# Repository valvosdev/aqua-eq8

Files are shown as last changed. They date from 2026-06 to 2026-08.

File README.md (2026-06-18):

# Aqua:eq8

> Open Hardware. Open Source. Smart Irrigation.

Aqua:eq8 is an open-source and open-hardware 8-zone smart irrigation controller designed for residential, commercial, greenhouse, and agricultural installations.

Built around the ESP32-C3-MINI-N4, Aqua:eq8 combines reliable irrigation control with secure connectivity, mobile management, OTA firmware updates, MQTT communication, and cloud integration while remaining fully self-hostable and hackable.

The project includes:

- ESP32 firmware
- Hardware schematics and PCB design
- Golang backend API
- React Native mobile application
- Docker, Kubernetes, and Helm deployment support

---

## Features

### Irrigation Control

- 8 independent irrigation zones
- Multiple zones can run simultaneously
- Configurable Master Valve support
- Configurable pump start delay
- Local manual operation without Internet
- Mobile application control
- MQTT-based communication
- Future scheduling support
- Future weather integration
- Emergency stop functionality

### Connectivity

- WiFi provisioning via BLE
- Bluetooth Low Energy onboarding
- MQTT communication
- OTA firmware updates
- Cloud synchronization
- Device telemetry

### Security

- ESP32 Secure Boot
- Flash Encryption
- Signed OTA updates
- TLS communication
- Device authentication
- Secure credential storage

### Reliability

- Offline-first operation
- Local control during Internet outages
- Hardware watchdog
- Software watchdog
- Automatic recovery
- Power-loss recovery

### Open Source

- Open firmware
- Open hardware
- Open API
- Open mobile app
- Self-hostable backend

---

# Repository Structure

```
aqua-eq8/
├── firmware/
│   ├── main/
│   ├── components/
│   ├── ble/
│   ├── wifi/
│   ├── mqtt/
│   ├── ota/
│   └── valve/
│
├── hardware/
│   ├── schematic/
│   ├── pcb/
│   ├── enclosure/
│   └── bom/
│
├── api/
│   ├── cmd/
│   ├── internal/
│   ├── deployments/
│   ├── helm/
│   └── docker/
│
├── mobile/
│   ├── src/
│   ├── ios/
│   └── android/
│
└── docs/

```

# Hardware

## Power

The controller is powered by a standard irrigation transformer.

### Input

text 24VAC Barrel Jack 

### Internal Rails

```
text 24VAC  ├── Valve Outputs  ├── Current Monitoring  └── AC/DC Converter       ├── 5V       └── 3.3V 
```
---

## Main Components

### MCU

- ESP32-C3-MINI-N4
- WiFi 2.4GHz
- Bluetooth Low Energy
- 4MB Flash

### Output Expansion

Two 74HC595 shift registers are used:

#### Shift Register #1

Controls:

- 8 TRIAC outputs
- 8 Green status LEDs

#### Shift Register #2

Controls:

- 8 Red Master LEDs

This minimizes GPIO usage while allowing future expansion.

### Valve Drivers

- TRIAC-based switching
- Designed for 24VAC sprinkler valves
- RC snubber protection per channel
- Future current sensing support

### Protection

- Input fuse
- Snubber protection on every channel
- Brownout protection
- Hardware watchdog
- Secure boot
- Flash encryption

---

# Channel Controls

## Channels 1-8

Each button controls one irrigation zone.

### Short Press

Toggle zone state.

| Current State | Action |
|---|---|
| OFF | Turn ON |
| ON | Turn OFF |

### Long Press

Toggle Master Valve assignment.

| Current State | Action |
|---|---|
| Normal Zone | Set as Master |
| Master Zone | Remove Master |

Only one channel may be configured as Master at a time.

---

# Master Valve Operation

A Master Valve is commonly used for:

- Main water supply
- Pump control
- Pressure system enable

When any non-master zone is enabled:

1. Master Valve turns ON immediately
2. Zone enters waiting state
3. Configurable delay timer starts
4. Zone activates after delay

Example:

text Channel 1 = Master  User enables Channel 3  Channel 1 ON immediately  Channel 3 LED flashes  5 second delay  Channel 3 ON 

When the last active zone stops:

text Channel 3 OFF  No active zones remaining  Channel 1 OFF 

### Default Delay

yaml master_delay_seconds: 5 

Configurable through the mobile application.

---

# Channel LED Behavior

Each channel button contains:

- Green LED
- Red LED

## Green LED

Indicates operational state.

| State | Green |
|---|---|
| OFF | OFF |
| Waiting Master Delay | Flashing |
| Active | Solid |

## Red LED

Indicates configuration state.

| State | Red |
|---|---|
| Normal Zone | OFF |
| Master Zone | Solid |

## Combined States

| State | Green | Red |
|---|---|---|
| OFF | OFF | OFF |
| ON | ON | OFF |
| Master OFF | OFF | ON |
| Master ON | ON | ON |
| Waiting Delay | Flashing | OFF |

---

# Status Button (Button 9)

Button 9 is a dedicated RGB status and management button.

Functions:

- Device Status
- BLE Pairing
- Factory Reset

---

## RGB Status LED

The status LED always displays the highest priority state.

Priority:

text Error OTA Update BLE Connected BLE Advertising WiFi Connected Booting 

### States

| State | RGB |
|---|---|
| Booting | White Breathing |
| WiFi Connected | Solid Green |
| BLE Advertising | Blue Breathing |
| Mobile App Connected | Solid Blue |
| OTA Update | Purple Breathing |
| Error | Red Flashing |

---

## Button Actions

### Short Press

Enable BLE pairing mode.

LED:

text Blue Breathing 

Duration:

text 10 Minutes 

### Long Press (10 Seconds)

Factory Reset.

Deletes:

- WiFi Credentials
- MQTT Configuration
- Device Pairing
- Local Configuration
- Schedules

LED:

text Red Breathing 

Device automatically reboots.

---

# Connectivity

Aqua:eq8 intentionally avoids:

- Captive Portals
- Access Point Setup
- Embedded Web UI

All device provisioning is performed through Bluetooth Low Energy.

### Provisioning Flow

text Power Device       ↓ Press Status Button       ↓ BLE Pairing       ↓ Mobile App       ↓ Send WiFi Credentials       ↓ Connect to Network       ↓ Register with Backend       ↓ MQTT Connected 

---

# MQTT

MQTT is the primary communication mechanism between the controller and backend services.

## Topics

text aquaeq8/{deviceId}/state aquaeq8/{deviceId}/events aquaeq8/{deviceId}/telemetry aquaeq8/{deviceId}/command aquaeq8/{deviceId}/ota 

## Example Telemetry

json {   "uptime": 86400,   "wifi_rssi": -62,   "free_heap": 124832,   "active_zones": [2,4,7] } 

MQTT data can be consumed directly by:

- Telegraf
- InfluxDB
- TimescaleDB
- VictoriaMetrics
- Grafana

---

# Firmware

Location:

text /firmware 

Built using:

- ESP-IDF
- FreeRTOS
- C/C++

## Features

### Device Control

- Zone management
- Master Valve logic
- Delay handling
- Local operation

### Connectivity

- BLE provisioning
- WiFi management
- MQTT client

### OTA

- Signed firmware updates
- Rollback protection
- Secure update process

### Security

- Secure Boot
- Flash Encryption
- Device authentication

### Reliability

- Hardware watchdog
- Software watchdog
- Crash recovery

---

# Backend API

Location:

text /api 

Built using:

- Go 1.26+
- PostgreSQL
- Redis
- MQTT

## Features

### Device Management

- Device registration
- Pairing
- Configuration synchronization

### Monitoring

- Online/offline status
- Telemetry collection
- Device diagnostics

### Security

- JWT authentication
- TLS communication
- API rate limiting

---

# Deployment

## Docker

bash docker compose up -d 

## Kubernetes

bash kubectl apply -f deployments/ 

## Helm

bash helm install aquaeq8 ./helm 

---

# Mobile Application

Location:

text /mobile 

Built using:

- React Native
- TypeScript

## Features

### Device Setup

- BLE discovery
- WiFi provisioning
- Device pairing

### Device Management

- Zone control
- Master Valve configuration
- Delay configuration

### Monitoring

- Device health
- Connectivity status
- Telemetry visualization

### OTA

- Firmware update notifications
- Update progress monitoring

---

# Future Features

## Planned

- Irrigation schedules
- Weather integration
- Rain delay
- Seasonal adjustments
- Water usage analytics

## Hardware Expansion

- Flow meter support
- Rain sensor input
- Valve current monitoring
- Leak detection
- Pump monitoring

---

# Valve Current Monitoring

Future versions may include electrical current sensing on each output channel.

Benefits:

- Detect disconnected valves
- Detect broken wires
- Detect short circuits
- Detect stuck valves
- Improve diagnostics

Example:

text Zone 4 ON  Expected Current: 220mA Measured Current: 0mA  Alert: Valve Not Connected 

---

# Development

## [Firmware](firmware)

bash cd firmware  idf.py build idf.py flash idf.py monitor 

## [Backend](api)

bash cd api  go run ./cmd/server 

## [Mobile](mobile)

bash cd mobile  yarn install

bash cd mobile  yarn install yarn start 

---

# Security Model

Every controller includes:

- Unique Device ID
- Device Certificate
- Private Key

Firmware security:

- Secure Boot enabled
- Flash Encryption enabled
- Signed OTA updates only

The controller never accepts unsigned firmware images.

---

# Contributing

Contributions are welcome.

Areas where help is needed:

- Embedded development
- Hardware design
- Backend development
- Mobile development
- Testing
- Documentation

Please open an issue or submit a pull request.

---

# License

MIT License

See [LICENSE](LICENSE) for details.

---

# Philosophy

Aqua:eq8 is built around three principles.

## Open Source

All software is publicly available.

## Open Hardware

PCB layouts and schematics are publicly available.

## Local First

Your irrigation system continues operating even if the Internet does not.

---

Aqua:eq8

An open-source, secure, MQTT-native irrigation controller built for modern gardens, farms, and greenhouses.

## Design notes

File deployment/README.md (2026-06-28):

# File file describe how to deploy the infrastructure on a kubernetes cluster.

``` kubectl create ns valvos ```

## MQTT

Run ``` ./generate-cert-key.sh ``` first to generate self signed certificates 

Create secrets for certs files

```
kubectl create secret generic mqtt-tls-certs \
  --from-file=valvos-dev-ca.crt=./certs/valvos-dev-ca.crt \
  --from-file=server-crt.crt=./certs/server.crt \
  --from-file=server-crt.key=./certs/server.key \
  -n valvos
```

``` helm upgrade -i mqtt t3n/mosquitto --namespace valvos  -f ./mqtt/values.yaml ```

### Test connectivity:

Replace the IP address with yours

```
mosquitto_sub -h 10.30.10.30 -p 8883 -t "tenant/0001000/device/1001001/zone/" \
  --cafile ./certs/valvos-dev-ca.crt \
  --cert ./certs/client.crt \
  --key ./certs/client.key \
  --insecure -v
```

Publish a message

```
 mosquitto_pub -h 10.30.10.30 -p 8883 -t "test/topic" \
  -m "Hello from macOS over MQTTS" \
  --cafile ./certs/valvos-dev-ca.crt \
  --cert ./certs/client.crt \
  --key ./certs/client.key \
  --insecure
  ```

mosquitto_pub -h 10.30.10.30 -p 8883 -t "tenant/0001000/device/1001003/zone/2/set" -d  \
  -m "1" \
  --cafile ./certs/valvos-dev-ca.crt \
  --cert ./certs/client.crt \
  --key ./certs/client.key \
  --insecure

mosquitto_pub -h 10.30.10.30 -p 8883 -t "tenant/0001000/device/1001003/master/set" \
  -m "0" \
  --cafile ./certs/valvos-dev-ca.crt \
  --cert ./certs/client.crt \
  --key ./certs/client.key \
  --insecure

 mosquitto_pub -h 10.30.10.30 -p 8883 -t "tenant/0001000/device/1001001/schedule/0/set" \
  -m '{"name":"Daytime Run","is_active":true,"steps":[{"zone":1,"time":420},{"zone":2,"time":600},{"zone":3,"time":420},{"zone":4,"time":600}]}' \
  --cafile ./certs/valvos-dev-ca.crt \
  --cert ./certs/client.crt \
  --key ./certs/client.key \
  --insecure

  mosquitto_pub -h 10.30.10.30 -p 8883 -t "tenant/0001000/device/1001001/schedule/1/set" \
  -m '{"name":"Quick Flush","is_active":true,"interval":10,"steps":[{"zone":1,"time":30},{"zone":2,"time":30},{"zone":3,"time":30},{"zone":4,"time":30}]}' \
  --cafile ./certs/valvos-dev-ca.crt \
  --cert ./certs/client.crt \
  --key ./certs/client.key \
  --insecure

  mosquitto_pub -h 10.30.10.30 -p 8883 -t "tenant/0001000/device/1001001/schedule/1/start" -m "" \
  --cafile ./certs/valvos-dev-ca.crt --cert ./certs/client.crt --key ./certs/client.key --insecure

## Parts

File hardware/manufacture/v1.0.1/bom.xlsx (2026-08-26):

Id | Designator | Footprint | Quantity | Designation
1 | BR1 | ABS10A13 | 1 | ABS10A-13
2 | C1, C22 | C_0603_1608Metric | 2 | 1uF
3 | C2, C3, C4, C5, C6, C7, C8, C9 | C_1206_3216Metric | 8 | 10nF
4 | C10, C11 | CP_Elec_5x5.7 | 2 | 10uF
5 | C12 | CP_Elec_10x10.5 | 1 | 47uF
6 | C13, C14 | C_0603_1608Metric | 2 | 2.2uF
7 | C15, C18, C21, C23 | C_0603_1608Metric | 4 | 0.1uF
8 | C16 | C_0603_1608Metric | 1 | 5.6nF
9 | C17 | C_0603_1608Metric | 1 | 12pF
10 | C19 | CP_Elec_5x5.7 | 1 | 47uF
11 | C20 | C_0603_1608Metric | 1 | 10uF
12 | C24 | C_0603_1608Metric | 1 | 22uF
13 | D1 | DO-214AA | 1 | D_TVS_Small_Filled
14 | D2, D3, D4, D5, D6, D7, D8, D9 | SOT-223 | 8 | Z0103MN
15 | D10 | D_SMB_Handsoldering | 1 | B360A-13-F
16 | F1 | Fuse_Bourns_MF-SM_7.98x5.44mm | 1 | Fuse
17 | J1 | PinHeader_2x03_P1.27mm_Vertical_SMD | 1 | Conn_02x03_Odd_Even
18 | J2 | TerminalBlock_Phoenix_MKDS-3-10-5.08_1x10_P5.08mm_Horizontal | 1 | Conn_01x10
19 | J3 | BarrelJack_Horizontal | 1 | Jack-DC
20 | L1 | L_7.3x7.3_H4.5 | 1 | 15uH
21 | R1, R2, R3, R4, R21, R66 | R_0603_1608Metric | 6 | 10k
22 | R5, R6, R7, R8, R9, R10, R11, R12, R23, R24, R25, R26, R27, R28, R37, R38, R39, R40, R41, R42, R43, R44, R45, R46 | R_0603_1608Metric | 24 | 470
23 | R13, R14, R15, R16, R17, R18, R19, R20 | R_1206_3216Metric | 8 | 330
24 | R22 | R_0603_1608Metric | 1 | 33
25 | R29, R30, R31, R32, R33, R34, R35, R36 | R_1206_3216Metric | 8 | 160
26 | R53, R54, R55, R56, R57, R58, R59 | R_0603_1608Metric | 7 | 1.8k
27 | R60, R61, R62 | R_0603_1608Metric | 3 | 150
28 | R63 | R_0603_1608Metric | 1 | 20k
29 | R64 | R_0805_2012Metric | 1 | 400k
30 | R65 | R_0603_1608Metric | 1 | 50k
31 | S1-S9 | 228EMVARGBFR | 9 | RGBFR_CH1_8_Status
41 | U1 | SOIC-8_5.3x6.2mm_P1.27mm | 1 | RT6362GSP
42 | U2 | XCVR_ESP32-C3-MINI-1-N4 | 1 | ESP32-C3-MINI-1-N4
43 | U3, U4 | SOIC-16W_5.3x10.2mm_P1.27mm | 2 | 74HC595
44 | U5, U6, U7, U8, U9, U10, U11, U12 | SMDIP-4_W7.62mm | 8 | FODM3053
45 | U13 | SOT-223-3_TabPin2 | 1 | AMS1117-3.3
46 | U14 | SOIC-8_3.9x4.9mm_P1.27mm | 1 | ACS725xLCTR-20AB

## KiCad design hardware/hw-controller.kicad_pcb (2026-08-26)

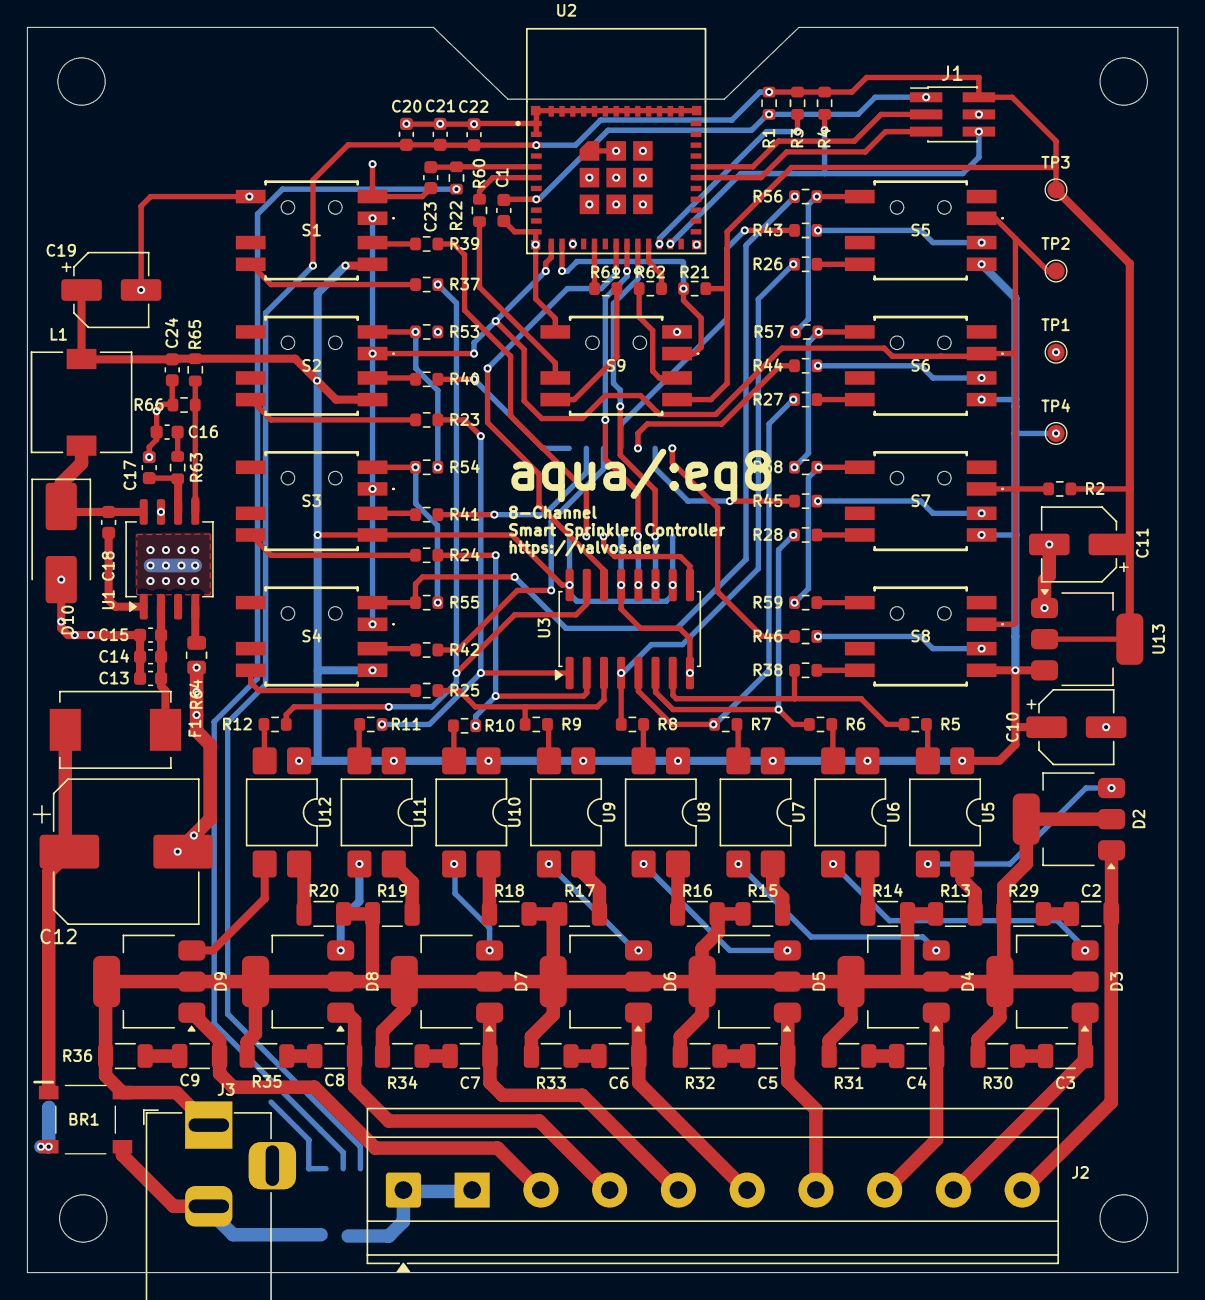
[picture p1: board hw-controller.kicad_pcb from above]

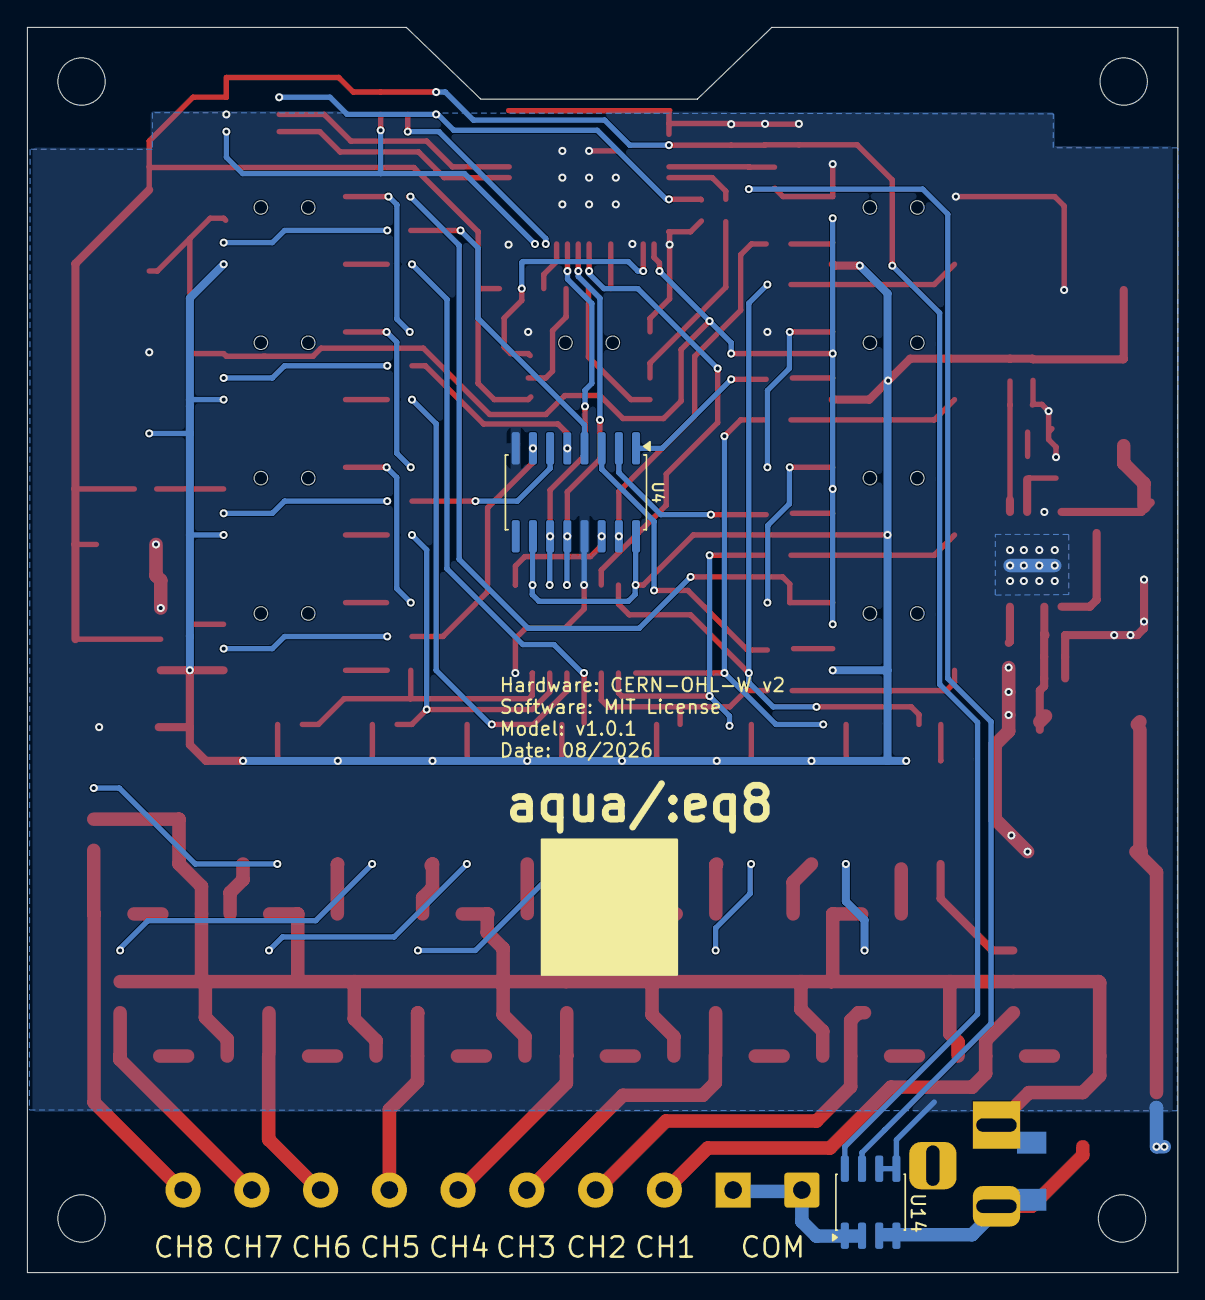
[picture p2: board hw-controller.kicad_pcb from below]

Board: 2 copper layers, 85.0 x 92.0 mm, 131 parts (3 on the bottom side), 112 nets.

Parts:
BR1: ABS10A-13; ABS10A13
C1, C22: 1uF; C_0603_1608Metric
C2, C3, C4, C5, C6, C7, C8, C9: 10nF; C_1206_3216Metric
C10, C11: 10uF; CP_Elec_5x5.7
C12: 47uF; CP_Elec_10x10.5
C13, C14: 2.2uF; C_0603_1608Metric
C15, C18, C21, C23: 0.1uF; C_0603_1608Metric
C16: 5.6nF; C_0603_1608Metric
C17: 12pF; C_0603_1608Metric
C19: 47uF; CP_Elec_5x5.7
C20: 10uF; C_0603_1608Metric
C24: 22uF; C_0603_1608Metric
D1: D_TVS_Small_Filled; DO-214AA
D2, D3, D4, D5, D6, D7, D8, D9: Z0103MN; SOT-223
D10: B360A-13-F; D_SMB_Handsoldering
F1: Fuse; Fuse_Bourns_MF-SM_7.98x5.44mm
H1, H2, H3, H4: MH; MountingHole_3.5mm
J1: Conn_02x03_Odd_Even; PinHeader_2x03_P1.27mm_Vertical_SMD
J2: Conn_01x10; TerminalBlock_Phoenix_MKDS-3-10-5.08_1x10_P5.08mm_Horizontal
J3: Jack-DC; BarrelJack_Horizontal
L1: 15uH; L_7.3x7.3_H4.5
R1, R2, R3, R4, R21, R66: 10k; R_0603_1608Metric
R5, R6, R7, R8, R9, R10, R11, R12, R23, R24, R25, R26, R27, R28, R37, R38, R39, R40, R41, R42, R43, R44, R45, R46: 470; R_0603_1608Metric
R13, R14, R15, R16, R17, R18, R19, R20: 330; R_1206_3216Metric
R22: 33; R_0603_1608Metric
R29, R30, R31, R32, R33, R34, R35, R36: 160; R_1206_3216Metric
R53, R54, R55, R56, R57, R58, R59: 1.8k; R_0603_1608Metric
R60, R61, R62: 150; R_0603_1608Metric
R63: 20k; R_0603_1608Metric
R64: 400k; R_0805_2012Metric
R65: 50k; R_0603_1608Metric
S1: RGBFR_CH1; 228EMVARGBFR
S2: RGBFR_CH2; 228EMVARGBFR
S3: RGBFR_CH3; 228EMVARGBFR
S4: RGBFR_CH4; 228EMVARGBFR
S5: RGBFR_CH5; 228EMVARGBFR
S6: RGBFR_CH6; 228EMVARGBFR
S7: RGBFR_CH7; 228EMVARGBFR
S8: RGBFR_CH8; 228EMVARGBFR
S9: RGBFR_STATUS; 228EMVARGBFR
TP1, TP2, TP3, TP4: TP_1_27
U1: RT6362GSP; SOIC-8_5.3x6.2mm_P1.27mm
U2: ESP32-C3-MINI-1-N4; XCVR_ESP32-C3-MINI-1-N4
U3, U4: 74HC595; SOIC-16W_5.3x10.2mm_P1.27mm
U5, U6, U7, U8, U9, U10, U11, U12: FODM3053; SMDIP-4_W7.62mm
U13: AMS1117-3.3; SOT-223-3_TabPin2
U14: ACS725xLCTR-20AB; SOIC-8_3.9x4.9mm_P1.27mm

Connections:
+3.3V: C11.1, C20.1, C21.1, C22.1, J1.2, R1.1, R2.1, R3.1, R4.1, R21.1, S9.L1 (COM_A), TP3.1 (TP_1), U2.3 (3V3), U13.2 (VO), U14.8 (VCC)
+5V: C10.1, C19.1, C24.1, L1.2, R65.2, S1.L1 (COM_A), S2.L1 (COM_A), S3.L1 (COM_A), S4.L1 (COM_A), S5.L1 (COM_A), S6.L1 (COM_A), S7.L1 (COM_A), S8.L1 (COM_A), TP4.1 (TP_1), U3.10 (~SRCLR), U3.16 (VCC), U4.10 (~SRCLR), U4.16 (VCC), U5.1, U6.1, U7.1, U8.1, U9.1, U10.1, U11.1, U12.1, U13.3 (VI)
/24VAC1: BR1.2 (~_1), D1.2 (A2), D2.2 (A2), D2.4 (A4), D3.2 (A2), D3.4 (A4), D4.2 (A2), D4.4 (A4), D5.2 (A2), D5.4 (A4), D6.2 (A2), D6.4 (A4), D7.2 (A2), D7.4 (A4), D8.2 (A2), D8.4 (A4), D9.2 (A2), D9.4 (A4), J3.1, R13.2, R14.2, R15.1, R16.2, R17.1, R18.2, R19.1, R20.2, R29.1, R30.1, R31.1, R32.1, R33.1, R34.1, R35.1, R36.1
/24VAC2: BR1.4 (~_2), D1.1 (A1), J3.2, U14.3 (IP-), U14.4 (IP-)
/24VAC2_OUT: J2.1, J2.2, U14.1 (IP+), U14.2 (IP+)
ACS_ADC: C23.1, R22.2, U2.5 (IO2)
BTNS_PIN: R2.2, S1.A1 (COM), S2.A1 (COM), S3.A1 (COM), S4.A1 (COM), S5.A1 (COM), S6.A1 (COM), S7.A1 (COM), S8.A1 (COM), TP2.1 (TP_1), U2.12 (IO0)
EN: C1.1, J1.1, R1.2, U2.8 (EN)
GND: BR1.3 (-), C1.2, C10.2, C11.2, C12.2, C13.2, C14.2, C15.2, C16.1, C17.1, C19.2, C20.2, C21.2, C22.2, C23.2, C24.2, D10.2 (A), J1.4, R53.2, R64.1, R66.1, S1.B1 (NO_1), S1.B2 (NO_2), S9.B1 (NO_1), S9.B2 (NO_2), TP1.1 (TP_1), U1.7 (GND), U2.1 (GND), U2.2 (GND), U2.11 (GND), U2.14 (GND), U2.36 (GND), U2.37 (GND), U2.38 (GND), U2.39 (GND), U2.40 (GND), U2.41 (GND), U2.42 (GND), U2.43 (GND), U2.44 (GND), U2.45 (GND), U2.46 (GND), U2.47 (GND), U2.48 (GND), U2.49_1 (GND), U2.49_2 (GND), U2.49_3 (GND), U2.49_4 (GND), U2.49_5 (GND), U2.49_6 (GND), U2.49_7 (GND), U2.49_8 (GND), U2.49_9 (GND), U2.50 (GND), U2.51 (GND), U2.52 (GND), U2.53 (GND), U3.8 (GND), U3.13 (~OE), U4.8 (GND), U4.13 (~OE), U13.1 (GND), U14.5 (GND), U14.6 (FILTER)
LATCH: U2.19 (IO5), U3.12 (RCLK), U4.12 (RCLK)
LEDG_CH1: R39.2, U4.15 (QA)
LEDG_CH2: R40.2, U4.1 (QB)
LEDG_CH3: R41.2, U4.2 (QC)
LEDG_CH4: R42.2, U4.3 (QD)
LEDG_CH5: R43.1, U4.4 (QE)
LEDG_CH6: R44.1, U4.5 (QF)
LEDG_CH7: R45.1, U4.6 (QG)
LEDG_CH8: R46.1, U4.7 (QH)
LEDR_CH1: R12.2, R37.2, U3.15 (QA)
LEDR_CH2: R11.2, R23.2, U3.1 (QB)
LEDR_CH3: R10.2, R24.2, U3.2 (QC)
LEDR_CH4: R9.1, R25.2, U3.3 (QD)
LEDR_CH5: R8.1, R26.1, U3.4 (QE)
LEDR_CH6: R7.1, R27.1, U3.5 (QF)
LEDR_CH7: R6.1, R28.1, U3.6 (QG)
LEDR_CH8: R5.1, R38.1, U3.7 (QH)
unnamed: BR1.1 (+), C12.1, F1.1
unnamed: C2.1, R29.2
unnamed: C3.1, R30.2
unnamed: C4.1, R31.2
unnamed: C5.1, R32.2
unnamed: C6.1, R33.2
unnamed: C7.1, R34.2
unnamed: C8.1, R35.2
unnamed: C9.1, R36.2
unnamed: C16.2, R63.1
unnamed: C2.2, D2.1 (A1), J2.10
unnamed: D2.3 (G), U5.3
unnamed: C3.2, D3.1 (A1), J2.9
unnamed: D3.3 (G), U6.3
unnamed: C4.2, D4.1 (A1), J2.8
unnamed: D4.3 (G), U7.3
unnamed: C5.2, D5.1 (A1), J2.7
unnamed: D5.3 (G), U8.3
unnamed: C6.2, D6.1 (A1), J2.6
unnamed: D6.3 (G), U9.3
unnamed: C7.2, D7.1 (A1), J2.5
unnamed: D7.3 (G), U10.3
unnamed: C8.2, D8.1 (A1), J2.4
unnamed: D8.3 (G), U11.3
unnamed: C9.2, D9.1 (A1), J2.3
unnamed: D9.3 (G), U12.3
unnamed: C18.2, D10.1 (K), L1.1, U1.8 (SW)
unnamed: R5.2, U5.2
unnamed: R6.2, U6.2
unnamed: R7.2, U7.2
unnamed: R8.2, U8.2
unnamed: R9.2, U9.2
unnamed: R10.1, U10.2
unnamed: R11.1, U11.2
unnamed: R12.1, U12.2
unnamed: R13.1, U5.4
unnamed: R14.1, U6.4
unnamed: R15.2, U7.4
unnamed: R16.1, U8.4
unnamed: R17.2, U9.4
unnamed: R18.1, U10.4
unnamed: R19.2, U11.4
unnamed: R20.1, U12.4
unnamed: R39.1, S1.L2 (K_GREEN)
unnamed: R37.1, S1.L3 (K_RED)
unnamed: R40.1, S2.L2 (K_GREEN)
unnamed: R23.1, S2.L3 (K_RED)
unnamed: R53.1, R54.2, S2.B1 (NO_1), S2.B2 (NO_2)
unnamed: R41.1, S3.L2 (K_GREEN)
unnamed: R24.1, S3.L3 (K_RED)
unnamed: R54.1, R55.2, S3.B1 (NO_1), S3.B2 (NO_2)
unnamed: R42.1, S4.L2 (K_GREEN)
unnamed: R25.1, S4.L3 (K_RED)
unnamed: R55.1, R56.1, S4.B1 (NO_1), S4.B2 (NO_2)
unnamed: R43.2, S5.L2 (K_GREEN)
unnamed: R26.2, S5.L3 (K_RED)
unnamed: R56.2, R57.1, S5.B1 (NO_1), S5.B2 (NO_2)
unnamed: R44.2, S6.L2 (K_GREEN)
unnamed: R27.2, S6.L3 (K_RED)
unnamed: R57.2, R58.1, S6.B1 (NO_1), S6.B2 (NO_2)
unnamed: R45.2, S7.L2 (K_GREEN)
unnamed: R28.2, S7.L3 (K_RED)
unnamed: R58.2, R59.1, S7.B1 (NO_1), S7.B2 (NO_2)
unnamed: R46.2, S8.L2 (K_GREEN)
unnamed: R38.2, S8.L3 (K_RED)
unnamed: R59.2, S8.B1 (NO_1), S8.B2 (NO_2)
unnamed: R60.2, S9.L4 (K_BLUE)
unnamed: R62.2, S9.L2 (K_GREEN)
unnamed: R61.2, S9.L3 (K_RED)
unnamed: C18.1, U1.1 (BOOT)
unnamed: C17.2, R63.2, U1.6 (COMP)
unnamed: R65.1, R66.2, U1.5 (FB)
unnamed: R64.2, U1.4 (RT/SYNC)
unnamed: C13.1, C14.1, C15.1, F1.2, U1.2 (VIN)
unnamed: U3.9 (QH'), U4.14 (SER)
unnamed: R22.1, U14.7 (VIOUT)
RX: J1.5, U2.30 (RXD0)
SCL: J1.6, R4.2, U2.23 (IO9)
SDA: R3.2, U2.22 (IO8)
SIPO_DATA: U2.18 (IO4), U3.14 (SER)
SIPO_SCK: U2.20 (IO6), U3.11 (SRCLK), U4.11 (SRCLK)
STATUS_BTN_PIN: R21.2, S9.A1 (COM), U2.13 (IO1)
STATUS_LEDB_PIN: R60.1, U2.6 (IO3)
STATUS_LEDG_PIN: R62.1, U2.21 (IO7)
STATUS_LEDR_PIN: R61.1, U2.16 (IO10)
TX: J1.3, U2.31 (TXD0)

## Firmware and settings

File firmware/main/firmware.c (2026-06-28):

#include <time.h>
#include "esp_log.h"
#include "esp_system.h"
#include "nvs_flash.h"
#include "esp_wifi.h"
#include "esp_event.h"

// ESP-IDF v6 Unified Provisioning Headers
#include "network_provisioning/manager.h"
#include "network_provisioning/scheme_ble.h"
#include "esp_sntp.h"  

#include "freertos/FreeRTOS.h"
#include "freertos/task.h"
#include "shift_reg_74hc595.h"
#include "adc_buttons.h"
#include "zone_controller.h"
#include "device_status.h"
#include "device_config.h"
#include "device_mqtt.h"
#include "device_schedule.h"

#define BTNS_PIN GPIO_NUM_0
#define LATCH GPIO_NUM_5
#define CLOCK GPIO_NUM_6
#define DATA GPIO_NUM_7

#define STATUS_BTN GPIO_NUM_1
#define STATUS_RED GPIO_NUM_2
#define STATUS_GREEN GPIO_NUM_3
#define STATUS_BLUE GPIO_NUM_4

#define PROV_POP "12345678"
#define PROV_PREFIX "VALVOS_AQUA8_"

static const char *APP_TAG = "app_main";
static zone_controller_handle_t global_zone_engine = NULL;
static device_status_handle_t global_status_engine = NULL;

// --- Pre-computed Cryptographic SRP6a Security 2 tokens for PIN "12345678" ---
static const char sec2_salt[] = {
    0xd2, 0xb4, 0xeb, 0xd0, 0x44, 0x6c, 0x03, 0x78, 0x24, 0x93, 0x21, 0x53, 0x33, 0xf3, 0x07, 0x61};

static const char sec2_verifier[] = {
    0x0c, 0xc4, 0xfd, 0x46, 0x5c, 0xb8, 0x0f, 0x0d, 0x37, 0x6e, 0x5e, 0xcb, 0x1f, 0x66, 0x2d, 0x05,
    0x7b, 0xfc, 0x2b, 0xfb, 0x1d, 0x9f, 0x77, 0x8f, 0x01, 0xe4, 0xe0, 0xea, 0xd3, 0x96, 0x00, 0x1d,
    0xc3, 0x14, 0x3c, 0x0b, 0x79, 0xe6, 0xe8, 0x2f, 0x5e, 0x73, 0xd9, 0xa2, 0x51, 0xa0, 0xa4, 0x10,
    0xac, 0x72, 0xcd, 0x59, 0x7a, 0x34, 0x57, 0x4b, 0xe9, 0x86, 0x28, 0x89, 0x83, 0x77, 0xb6, 0xde,
    0xd0, 0xed, 0x92, 0x9f, 0x73, 0xf1, 0xf9, 0x07, 0xa8, 0xed, 0xcf, 0x27, 0xff, 0x66, 0x2a, 0x4d,
    0x4e, 0x42, 0x0e, 0x03, 0xb4, 0x3f, 0xe3, 0x39, 0x81, 0x96, 0xfb, 0x3f, 0x35, 0x2d, 0x6a, 0x58,
    0x1c, 0x5a, 0x16, 0x74, 0xea, 0x01, 0x4f, 0xbe, 0xba, 0x41, 0x02, 0x38, 0x1c, 0x7a, 0x97, 0xf9,
    0x86, 0xbf, 0x0e, 0x1e, 0x4e, 0x50, 0xef, 0xb6, 0xac, 0x97, 0x62, 0x2c, 0xb2, 0x8f, 0x37, 0xea,
    0x56, 0x95, 0x4c, 0xc7, 0xa1, 0x2f, 0xb6, 0x6b, 0xd6, 0xab, 0x20, 0xbc, 0x1f, 0x65, 0x9e, 0x60,
    0x87, 0x27, 0x32, 0xf9, 0xbd, 0xfd, 0x76, 0x09, 0x24, 0x34, 0x5c, 0xbe, 0xb1, 0x47, 0x50, 0xf5,
    0xaf, 0xb6, 0x42, 0x5b, 0xab, 0xac, 0xf4, 0xe8, 0xf9, 0xaa, 0x58, 0xd1, 0x63, 0xda, 0x8a, 0xa3,
    0x8e, 0x5e, 0xec, 0x36, 0x55, 0x04, 0xe6, 0x57, 0x3d, 0xa0, 0x4b, 0xc4, 0x7c, 0xd8, 0xcc, 0xef,
    0x97, 0x53, 0xf7, 0x94, 0xcb, 0x69, 0x03, 0xaf, 0x74, 0xfa, 0x37, 0xa5, 0xd7, 0xd2, 0xa4, 0x6d,
    0x3d, 0x9e, 0x1b, 0xfa, 0x1b, 0xef, 0x87, 0x7e, 0x5f, 0xb6, 0x57, 0x70, 0x27, 0xfb, 0x65, 0x0a,
    0xef, 0xa2, 0x3f, 0xc3, 0xf8, 0xd7, 0x78, 0x71, 0x9d, 0x25, 0x08, 0x47, 0xd0, 0x5a, 0xa2, 0xbf,
    0x56, 0x95, 0x3f, 0x00, 0x52, 0x5d, 0x6d, 0x2a, 0xaf, 0x17, 0x0f, 0x87, 0x40, 0x33, 0x16, 0x7a,
    0x39, 0x20, 0x9f, 0xe7, 0x4d, 0x0b, 0x2b, 0x87, 0xc7, 0xc3, 0x96, 0xae, 0x29, 0xe8, 0xe2, 0x95,
    0x97, 0x08, 0xbe, 0x94, 0x90, 0x15, 0x61, 0xd9, 0xbd, 0x59, 0x72, 0x83, 0xd9, 0xa4, 0x1a, 0xf4,
    0x5f, 0x52, 0x0a, 0x4c, 0xac, 0xe6, 0xd0, 0x74, 0x2a, 0x56, 0x83, 0xe3, 0x49, 0xc0, 0x51, 0x29,
    0xb2, 0xac, 0xaf, 0xbd, 0x6f, 0x6b, 0x37, 0xfc, 0xc8, 0x1e, 0x49, 0xb4, 0xe3, 0x3d, 0x76, 0xd4,
    0xde, 0xcf, 0xc0, 0xbc, 0xc2, 0xaa, 0x2f, 0x98, 0x04, 0xa7, 0x63, 0xf7, 0xdb, 0x75, 0x03, 0xd4,
    0x4b, 0x55, 0x31, 0x5d, 0x97, 0x3b, 0x36, 0x94, 0x07, 0x3a, 0xb5, 0xb9, 0xcf, 0x76, 0x3f, 0x6a,
    0xe3, 0x0e, 0xb3, 0x40, 0xff, 0x40, 0x07, 0x94, 0xc3, 0x44, 0x9f, 0x28, 0x7b, 0x26, 0xbc, 0x16,
    0x4b, 0x76, 0x67, 0x25, 0xec, 0xbb, 0x38, 0x18, 0x17, 0x8e, 0x5f, 0xb6, 0x4e, 0x28, 0xe8, 0x30};


static void on_time_synchronized(struct timeval *tv)
{
    ESP_LOGW("app_main", "Time synchronization validated via SNTP cluster.");
    
    device_runtime_config_t runtime_conf;
    if (device_config_load_from_nvs(&runtime_conf) == ESP_OK) {
        // Safe linear boot dependency injection
        ESP_ERROR_CHECK(device_mqtt_start(&runtime_conf, global_zone_engine));
    } else {
        ESP_LOGE("app_main", "Critical: NVS config corrupt. Cannot mount secure MQTT layer.");
    }
}

static void wifi_and_prov_event_handler(void *arg, esp_event_base_t event_base, int32_t event_id, void *event_data)
{
    if (event_base == NETWORK_PROV_EVENT)
    {
        switch (event_id)
        {
        case NETWORK_PROV_START:
            ESP_LOGI(APP_TAG, "Secure BLE Portal Active. Open ESP Prov App and use PIN 12345678.");
            device_status_set_state(global_status_engine, STATUS_STATE_BLE_ADVERTISING, true);
            break;
        case NETWORK_PROV_WIFI_CRED_RECV:
        {
            wifi_sta_config_t *wifi_config = (wifi_sta_config_t *)event_data;
            ESP_LOGI(APP_TAG, "Received encrypted configuration for SSID: %s", (char *)wifi_config->ssid);
            break;
        }
        case NETWORK_PROV_WIFI_CRED_FAIL:
            ESP_LOGE(APP_TAG, "Provisioning handshake authentication failed.");
            device_status_set_state(global_status_engine, STATUS_STATE_ERROR, true);
            break;
        case NETWORK_PROV_END:
            ESP_LOGI(APP_TAG, "Provisioning finalized cleanly. Releasing secure BLE layer.");
            device_status_set_state(global_status_engine, STATUS_STATE_BLE_ADVERTISING, false);
            network_prov_mgr_deinit();
            break;
        default:
            break;
        }
    }
    else if (event_base == WIFI_EVENT)
    {
        switch (event_id)
        {
        case WIFI_EVENT_STA_START:
            esp_wifi_connect();
            break;
        case WIFI_EVENT_STA_DISCONNECTED:
            wifi_event_sta_disconnected_t *disconn = (wifi_event_sta_disconnected_t *)event_data;
            ESP_LOGE(APP_TAG, "Wi-Fi disconnected. Reason code: %d", disconn->reason);
            // Change Status LED to show error/reconnecting state
            device_status_set_state(global_status_engine, STATUS_STATE_WIFI_CONNECTED, false);
            // Prevent spamming the router: Wait out a 3-second recovery backoff delay
            vTaskDelay(pdMS_TO_TICKS(3000));

            // Reconnect safely
            esp_wifi_connect();
            break;
        default:
            break;
        }
    }
    else if (event_base == IP_EVENT && event_id == IP_EVENT_STA_GOT_IP)
    {
        ip_event_got_ip_t *event = (ip_event_got_ip_t *)event_data;
        ESP_LOGI(APP_TAG, "Connected securely! IP Address: " IPSTR, IP2STR(&event->ip_info.ip));

        device_status_set_state(global_status_engine, STATUS_STATE_BOOTING, false);
        device_status_set_state(global_status_engine, STATUS_STATE_WIFI_CONNECTED, true);
        
        // Fire up background clock manager routines 
        esp_sntp_setoperatingmode(SNTP_OPMODE_POLL);
        esp_sntp_setservername(0, "pool.ntp.org");
        sntp_set_time_sync_notification_cb(on_time_synchronized);
        esp_sntp_init();
    
    }
}

void sprinkler_on_handler(uint8_t zone, void *ctx)
{
    // The internal engine layer is 0-indexed (0-7).
    // Shift to 1-based index (1-8) for user readability and MQTT formatting alignment.
    uint8_t standard_zone = zone + 1;
    ESP_LOGW(APP_TAG, ">>> TRIAC ENGAGED: Sprinkler valve %d open! <<<", standard_zone);

    // Send visual state update packet out over the network automatically
    device_mqtt_publish_status("zone_on", standard_zone);
}

void sprinkler_off_handler(uint8_t zone, void *ctx)
{
    uint8_t standard_zone = zone + 1;
    ESP_LOGI(APP_TAG, ">>> TRIAC DISENGAGED: Sprinkler valve %d closed.", standard_zone);

    device_mqtt_publish_status("zone_off", standard_zone);
}

void master_assigned_handler(uint8_t zone, void *ctx)
{
    uint8_t human_zone = zone;
    ESP_LOGE(APP_TAG, "!!! Zone %d took Master control !!!", human_zone);

    device_runtime_config_t current_conf;

    // Attempt to load from NVS. If it fails because it's empty, initialize with defaults!
    esp_err_t err = device_config_load_from_nvs(&current_conf);
    if (err == ESP_ERR_NVS_NOT_FOUND)
    {
        ESP_LOGW(APP_TAG, "NVS space empty. Initializing clean default configuration profile layout...");
        memset(&current_conf, 0, sizeof(device_runtime_config_t));
        // Assign basic default string bounds safely to prevent pointer corruption
        strcpy(current_conf.tenant_id, "0001000");
        strcpy(current_conf.device_id, "1001001");
        strcpy(current_conf.mqtt_url, "mqtts://10.30.10.30:8883");
        current_conf.master_delay_sec = 5; // Default 5
    }

    // Always apply the new master channel change
    current_conf.master_ch = (int8_t)human_zone;
    current_conf.master_delay_sec = 5; // Default 5
    // Commit to flash partition
    err = device_config_save_to_nvs(&current_conf);
    if (err == ESP_OK)
    {
        ESP_LOGI(APP_TAG, "NVS Storage Updated: Master Valve saved as Channel %d.", human_zone);
    }
    else
    {
        ESP_LOGE(APP_TAG, "Failed to preserve master configuration into flash memory.");
    }

    // Broadcast the status update back to the network dashboard
    device_mqtt_publish_status("master_update", human_zone);
}

void app_button_bridge_handler(uint8_t button_index, adc_button_event_t event, void *user_ctx)
{
    zone_controller_handle_t engine = (zone_controller_handle_t)user_ctx;
    if (engine)
    {
        zone_controller_handle_button_event(engine, button_index, event);
    }
}

void start_first_schedule(void) {
    // SHORT PRESS ON CONTROL/STATUS BUTTON TRIGGERS FIRST SCHEDULE PROFILE RUN
    ESP_LOGW(APP_TAG, "Control button short-pressed. Running the first schedule sequence sequence...");
    
    // Executes the default 7-minute factory sequence automatically
    esp_err_t err = device_schedule_start_by_index(0); 
    if (err == ESP_ERR_INVALID_STATE) {
        ESP_LOGE(APP_TAG, "A sequence is already active. Stopping execution task.");
        device_schedule_stop_current(); // Toggles off if double clicked
    }
}

void pairing_mode_started(void)
{
    ESP_LOGW(APP_TAG, "Manual Pairing Window Requested via Button...");
    bool provisioned = false;
    network_prov_mgr_is_wifi_provisioned(&provisioned);

    if (!provisioned)
    {
        ESP_LOGI(APP_TAG, "Device is unconfigured. BLE portal is already active.");
    }
    else
    {
        ESP_LOGW(APP_TAG, "Re-launching Secure BLE Portal...");

        network_prov_security2_params_t sec2_params = {
            .salt = sec2_salt,
            .salt_len = sizeof(sec2_salt),
            .verifier = sec2_verifier,
            .verifier_len = sizeof(sec2_verifier),
        };

        network_prov_mgr_start_provisioning(NETWORK_PROV_SECURITY_2, (const void *)&sec2_params, PROV_PREFIX, NULL);
    }
}

void factory_reset_wiping_sequence(void)
{
    ESP_LOGE(APP_TAG, "!!! FACTORY RESET ENGAGED: PURGING ALL ALLOCATED MEMORY PARTITIONS !!!");
    nvs_flash_erase();
    vTaskDelay(pdMS_TO_TICKS(3000));
    esp_restart();
}

esp_err_t custom_config_prov_handler(uint32_t session_id, const uint8_t *in_data, ssize_t in_len,
                                     uint8_t **out_data, ssize_t *out_len, void *priv_data)
{
    // One line completely handles validation, parsing, safety checks, and saving to flash memory
    esp_err_t err = device_config_update_from_json((const char *)in_data, in_len);
    if (err != ESP_OK)
        return ESP_FAIL;

    *out_data = (uint8_t *)strdup("{\"status\":\"config_applied\"}");
    *out_len = strlen((char *)*out_data);
    return ESP_OK;
}


void app_main(void)
{

    shift_reg_handle_t sr_device = NULL;
    adc_buttons_handle_t btn_device = NULL;
    device_runtime_config_t system_conf;
    esp_err_t err;

    err = nvs_flash_init();
    if (err == ESP_ERR_NVS_NO_FREE_PAGES || err == ESP_ERR_NVS_NEW_VERSION_FOUND)
    {
        ESP_ERROR_CHECK(nvs_flash_erase());
        err = nvs_flash_init();
    }
    ESP_ERROR_CHECK(err);

    ESP_ERROR_CHECK(esp_event_loop_create_default());
    ESP_ERROR_CHECK(esp_netif_init());

    shift_reg_config_t sr_cfg = {
        .pin_ds = DATA,
        .pin_shcp = CLOCK,
        .pin_stcp = LATCH,
        .polarity = SHIFT_REG_INDIRECT};
    ESP_ERROR_CHECK(shift_reg_init(&sr_cfg, &sr_device));

    zone_controller_config_t zone_cfg = {
        .sr_handle = sr_device,
        .btn_handle = NULL,
        .on_zone_activated = sprinkler_on_handler,
        .on_zone_deactivated = sprinkler_off_handler,
        .on_master_assigned = master_assigned_handler,
        .user_ctx = NULL};
    ESP_ERROR_CHECK(zone_controller_init(&zone_cfg, &global_zone_engine));

    adc_buttons_config_t btn_cfg = {
        .gpio_num = BTNS_PIN,
        .short_press_threshold_ms = 50,
        .long_press_threshold_ms = 1200,
        .voltage_tolerance_mv = 75,
        .callback = app_button_bridge_handler,
        .user_ctx = global_zone_engine,
        .expected_mv = {4, 542, 938, 1249, 1502, 1701, 1866, 2007}};
    ESP_ERROR_CHECK(adc_buttons_init(&btn_cfg, &btn_device));

    device_status_config_t status_cfg = {
        .pin_btn = STATUS_BTN,
        .pin_red = STATUS_RED,
        .pin_green = STATUS_GREEN,
        .pin_blue = STATUS_BLUE,
        .callbacks = {
            .on_short_press = start_first_schedule,
            .on_very_very_long_press = factory_reset_wiping_sequence}};
    ESP_ERROR_CHECK(device_status_init(&status_cfg, &global_status_engine));

    
    ESP_ERROR_CHECK(device_schedule_init(global_zone_engine));

    // CALL THE COMPONENT METHOD TO READ FLASH HERE:
    if (device_config_load_from_nvs(&system_conf) == ESP_OK)
    {

        // Set your local system time-keeping zone profile
        if (strlen(system_conf.timezone) > 0)
        {
            setenv("TZ", system_conf.timezone, 1);
            tzset();
        }

        // Immediately apply NVS rules directly to the operational engine
        zone_controller_set_master(global_zone_engine, system_conf.master_ch);
        zone_controller_set_master_delay(global_zone_engine, system_conf.master_delay_sec);

        ESP_LOGI(APP_TAG, "NVS Config applied: Master CH=%d, Delay=%lu sec",
                 system_conf.master_ch, system_conf.master_delay_sec);
    }

    esp_netif_create_default_wifi_sta();
    wifi_init_config_t cfg = WIFI_INIT_CONFIG_DEFAULT();
    ESP_ERROR_CHECK(esp_wifi_init(&cfg));

    ESP_ERROR_CHECK(esp_event_handler_register(NETWORK_PROV_EVENT, ESP_EVENT_ANY_ID, &wifi_and_prov_event_handler, NULL));
    ESP_ERROR_CHECK(esp_event_handler_register(WIFI_EVENT, ESP_EVENT_ANY_ID, &wifi_and_prov_event_handler, NULL));
    ESP_ERROR_CHECK(esp_event_handler_register(IP_EVENT, IP_EVENT_STA_GOT_IP, &wifi_and_prov_event_handler, NULL));

    ESP_ERROR_CHECK(esp_wifi_set_mode(WIFI_MODE_STA));

    wifi_config_t current_wifi_cfg;
    if (esp_wifi_get_config(WIFI_IF_STA, &current_wifi_cfg) == ESP_OK) {
        
        // 1. Set the minimum security threshold to standard WPA2
        current_wifi_cfg.sta.threshold.authmode = WIFI_AUTH_WPA2_PSK;
        
        // 2. CRITICAL FIX FOR MIXED MODE: Tell the ESP32-C3 to explicitly allow 
        // WPA3-SAE transition capability if the AP offers it.
        current_wifi_cfg.sta.sae_pwe_h2e = WPA3_SAE_PWE_BOTH; 
        
        // 3. Scan all available channels uniformly
        current_wifi_cfg.sta.scan_method = WIFI_ALL_CHANNEL_SCAN;
        current_wifi_cfg.sta.sort_method = WIFI_CONNECT_AP_BY_SIGNAL;
        
        // 4. Force PMF (Protected Management Frames) to Optional/Capable
        current_wifi_cfg.sta.pmf_cfg.capable = true;
        current_wifi_cfg.sta.pmf_cfg.required = false;
        
        ESP_ERROR_CHECK(esp_wifi_set_config(WIFI_IF_STA, &current_wifi_cfg));
        ESP_LOGI(APP_TAG, "WPA2/WPA3 Mixed Transition Mode profile successfully applied.");
    }

    ESP_ERROR_CHECK(esp_wifi_start());

    network_prov_mgr_config_t prov_config = {
        .scheme = network_prov_scheme_ble,
        .scheme_event_handler = {
            .event_cb = network_prov_scheme_ble_event_cb_free_ble,
            .user_data = NULL}};
    ESP_ERROR_CHECK(network_prov_mgr_init(prov_config));

    bool provisioned = false;
    ESP_ERROR_CHECK(network_prov_mgr_is_wifi_provisioned(&provisioned));

    if (!provisioned)
    {
        ESP_LOGW(APP_TAG, "Device not provisioned. Launching Secure BLE Provisioning Service...");

        uint8_t eth_mac[6] = {0};
        esp_wifi_get_mac(WIFI_IF_STA, eth_mac);
        char custom_prov_name[32] = {0};
        snprintf(custom_prov_name, sizeof(custom_prov_name), "%s%02X%02X", PROV_PREFIX, eth_mac[4], eth_mac[5]);

        network_prov_security2_params_t sec2_params = {
            .salt = sec2_salt,
            .salt_len = sizeof(sec2_salt),
            .verifier = sec2_verifier,
            .verifier_len = sizeof(sec2_verifier),
        };

        ESP_ERROR_CHECK(network_prov_mgr_endpoint_create("custom-config"));
        // Start provisioning using standard Security 2 authentication token
        ESP_ERROR_CHECK(network_prov_mgr_start_provisioning(NETWORK_PROV_SECURITY_2, (const void *)&sec2_params, custom_prov_name, NULL));
        ESP_ERROR_CHECK(network_prov_mgr_endpoint_register("custom-config", custom_config_prov_handler, NULL));
    }
    else
    {
        network_prov_mgr_deinit();

        ESP_LOGI(APP_TAG, "Saved network credentials found. Autoconnecting to Wi-Fi...");
        device_status_set_state(global_status_engine, STATUS_STATE_BOOTING, false);
        esp_wifi_connect();
    }

    ESP_LOGI(APP_TAG, "Sprinkler Controller Online.");

    while (1)
    {
        vTaskDelay(pdMS_TO_TICKS(1000));
    }
}

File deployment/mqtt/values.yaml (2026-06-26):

replicaCount: 1
strategyType: Recreate

image:
  repository: eclipse-mosquitto
  tag: 2.0.18
  pullPolicy: IfNotPresent

imagePullSecrets: []
nameOverride: ""
fullnameOverride: ""

serviceAccount:
  # Specifies whether a service account should be created
  create: true
  # The name of the service account to use.
  # If not set and create is true, a name is generated using the fullname template
  name:

service:
  type: NodePort
  externalTrafficPolicy: Cluster 
  annotations: {}
    # metallb.universe.tf/allow-shared-ip: pi-hole

ports:
  mqtt:
    port: 1883
    # sets consistent nodePort, required to set service.type=NodePort
    # nodePort: 31883
    protocol: TCP
  mqtts:
    port: 8883
    nodePort: 31883
    protocol: TCP
  websocket:
    port: 9001
    protocol: TCP

persistence:
  enabled: true
  accessMode: ReadWriteOnce
  existingClaim: ""
  mountPath: /mosquitto/data

  size: 1Gi


existingConfigMap: ""
config: |
  persistence true
  persistence_location /mosquitto/data/
  # WebSockets
  listener 9001 0.0.0.0
  protocol websockets

  # MQTTS (Encrypted or standard traffic listener)
  listener 8883 0.0.0.0

  cafile /mosquitto/config/certs/valvos-dev-ca.crt
  certfile /mosquitto/config/certs/server-crt.crt
  keyfile /mosquitto/config/certs/server-crt.key
  require_certificate true
  use_identity_as_username true
  
## Additional volumes.
extraVolumes: 
  - name: mqtt-tls-crt
    secret:
      secretName: mqtt-tls-certs
      items:
        - key: valvos-dev-ca.crt
          path: valvos-dev-ca.crt
        - key: server-crt.crt
          path: server-crt.crt
        - key: server-crt.key
          path: server-crt.key
# # ## Additional volumeMounts to the main container.
extraVolumeMounts: 
  - name: mqtt-tls-crt
    mountPath: /mosquitto/config/certs
    readOnly: true

monitoring:
  podMonitor:
    enabled: false
  sidecar:
    enabled: false
    port: 9234
    # nodePort: 32234
    image:
      repository: nolte/mosquitto-exporter
      tag: v0.6.3
      pullPolicy: IfNotPresent
    resources:
      limits:
        cpu: 300m
        memory: 128Mi
      requests:
        cpu: 100m
        memory: 64Mi

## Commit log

2026-06-18 refactored teh pcb , fixed: C12 - made TH Added ACS725 to read currect Replaced triacs with something smaller Z0103 IMPORTANT: esp pins been changed, not compatible with v1.0.0
    [hw-controller.kicad_pcb, hw-controller.kicad_sch, io.kicad_sch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]
2026-06-18 save changes
    [hw-controller.kicad_pcb]
2026-06-24 fixed the master set and unset, on master set/unset display a visual feedback. encrised mqtt time to retry the connection
    [firmware.c]
2026-06-25 changed some resistors and caps to 0603
    [hw-controller.kicad_pcb, hw-controller.kicad_sch, io.kicad_sch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]
2026-06-26 retrace, fixrule checker error
    [hw-controller.kicad_pcb, io.kicad_sch, output.kicad_sch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]
2026-06-26 generated bom, tried to unify components
    [bom.xlsx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]
2026-08-26 added script to start scheduler
    [bom.xlsx, hw-controller.kicad_pcb]

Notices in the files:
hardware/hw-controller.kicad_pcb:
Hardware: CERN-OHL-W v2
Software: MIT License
